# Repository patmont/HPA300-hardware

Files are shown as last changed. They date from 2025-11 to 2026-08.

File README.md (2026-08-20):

# HPA300 replacement controller hardware

An open-hardware, ESP32-S2 replacement control board for the Honeywell HPA300
air purifier. The board preserves the original front-panel layout while adding
USB-C, native USB programming, and a controller designed for the companion
[HPA300 firmware](https://github.com/patmont/HPA300-firmware).

<p align="center">
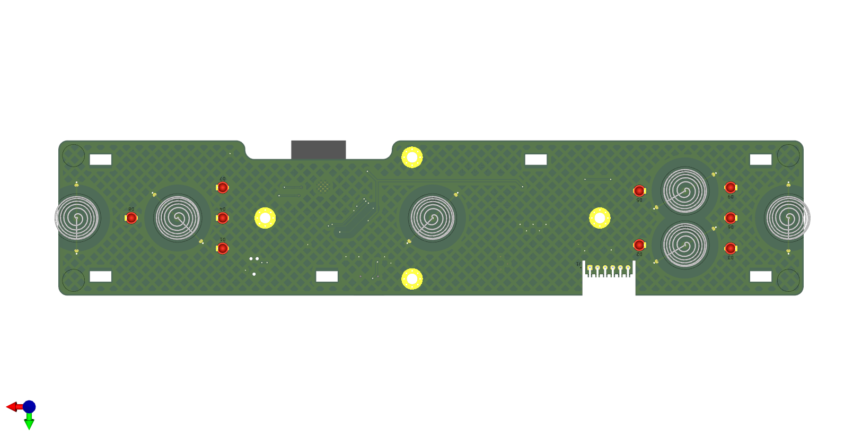
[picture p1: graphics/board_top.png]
HPA300 controller board, front view
  
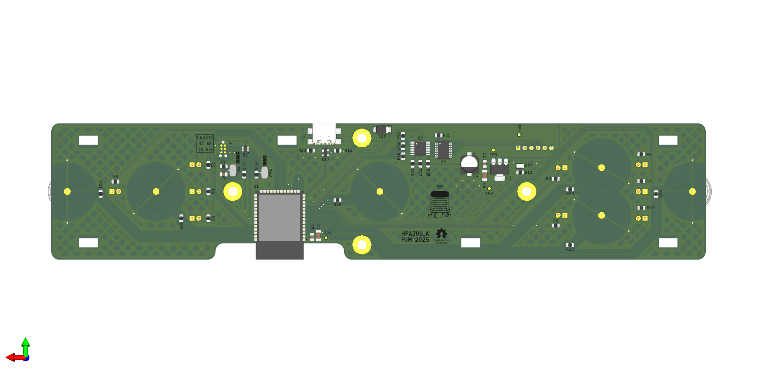
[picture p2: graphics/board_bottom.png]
HPA300 controller board, rear view
  
</p>

> [!IMPORTANT]
> This is an independent community project. It is not affiliated with,
> authorized by, or endorsed by Honeywell International Inc. Build and install
> it at your own risk.

## Downloads

| I want to... | Get this |
| --- | --- |
| Read the circuit | [Schematic PDF](HPA300.pdf) |
| Order the parts | [DigiKey shared list](https://www.digikey.com/en/mylists/list/1ANK154NOU) or [versioned BOM](manufacturing/Assembly/HPA300-bom.csv) |
| Order a bare PCB | Download the `HPA300-<version>-gerbers.zip` asset from the [latest release](https://github.com/patmont/HPA300-hardware/releases/latest) |
| Modify the design | Open [HPA300.kicad_pro](HPA300.kicad_pro) in KiCad 9 |
| Build or flash firmware | Visit [HPA300-firmware](https://github.com/patmont/HPA300-firmware) |

Release assets are the recommended manufacturing handoff because they are tied
to a tagged revision and include SHA-256 checksums. The files under
`manufacturing/` are reviewable snapshots; do not mix them with source files
from a different commit.

## Hardware overview

- ESP32-S2-SOLO-2 controller with native USB-C
- Six capacitive-touch keys matching the original control panel
- Nine front-panel indicators with PWM brightness control
- 74HC238 fan-speed selection with a hardware-disabled default state
- Boot, reset, Tag-Connect programming, and power test access
- Two-layer, 1.6 mm PCB designed in KiCad 9
- Approximately 245 mm × 51 mm overall outline, including the shaped edges

The current checked-in design is revision A and corresponds to the as-built
board. Before ordering, inspect the schematic, board outline, connector
orientation, and your purifier revision. This project has not been evaluated or
certified by a safety agency.

## Manufacturing

For a bare PCB, upload only the release's Gerber archive to the fabricator. It
contains copper, solder mask, paste, silkscreen, edge cuts, plated drills, and
non-plated drills. The archive is generated from the tracked files in
[`manufacturing/Fabrication`](manufacturing/Fabrication/).

The [DigiKey list](https://www.digikey.com/en/mylists/list/1ANK154NOU) is the
most convenient shopping list. The repository BOM is version controlled so a
release remains reproducible even if the shared list later changes. Check stock,
manufacturer part numbers, substitutions, and do-not-populate items before
ordering.

The current repository does **not** claim to be a turnkey PCBA package. An
assembly house will also need a placement/centroid file, confirmed rotations,
assembly drawings, and instructions for the through-hole and mechanical parts.
See [manufacturing/README.md](manufacturing/README.md) for the artifact manifest
and release procedure.

To build the same release assets locally from PowerShell:

```powershell
./scripts/package-release.ps1 -Version v0.1.0
```

The packages are written to `dist/`, which is intentionally ignored by Git.
Pushing a `v*` tag runs the same packager in GitHub Actions and creates a GitHub
release with the Gerber ZIP, schematic PDF, BOM, license notice, and checksum
manifest.

## Repository layout

```text
HPA300.kicad_pro         KiCad project entry point
HPA300.kicad_pcb         Editable PCB source
HPA300.kicad_sch         Root schematic and hierarchical sheets
*.kicad_sch
lib/                     Project-specific symbols, footprints, and 3D models
graphics/                Board renders, logo, and open-hardware mark
manufacturing/
  Fabrication/           Gerber and drill snapshot
  Assembly/              Version-controlled BOM
scripts/                 Reproducible release packaging
.github/workflows/       CI and tagged-release automation
```

KiCad backups, local preferences, caches, downloaded datasheets, and generated
release archives are excluded from version control. Custom symbols, footprints,
and 3D models required to open the project are kept in `lib/`.

## Contributing

Open an issue before making a change that affects the board outline, original
appliance interface, fan safety behavior, or manufacturing stack-up. For a
design change, update the editable KiCad source first, run KiCad's electrical
and design-rule checks, then regenerate the PDF, BOM, Gerbers, and drill files
together. Include the KiCad version and rule-check results in the pull request.

## License and attribution

The hardware design and associated source are licensed under the
[CERN Open Hardware Licence Version 2 – Weakly Reciprocal](LICENSE). You may
study, modify, make, and sell products based on the design, but the license
requires preservation of notices and corresponding-source obligations. See
[NOTICE.md](NOTICE.md) for the copyright, source-location, attribution, and
trademark notices that travel with the design.

Commercial use cannot be prohibited while also calling the project open-source
hardware. The reciprocal license and source-location notice are intended to
ensure that commercial derivatives remain attributable and that their design
changes are available to recipients.

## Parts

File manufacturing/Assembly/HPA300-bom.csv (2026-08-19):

Reference | Qty | Value | DNP | Exclude from BOM | Exclude from Board | Footprint | Datasheet | Digikey
C1 | 1 | 22uF |  |  |  | Capacitor_SMD:C_1206_3216Metric | ~ | CL31A226KAHNNNE
C2,C5 | 2 | 1uF |  |  |  | Capacitor_SMD:C_0805_2012Metric | ~ | GRM21BR61C105MA01L
C3 | 1 | 0.1uF |  |  |  | Capacitor_SMD:C_0805_2012Metric | ~ | KGM21KR51H104KU
C4 | 1 | 100uF |  |  |  | Capacitor_SMD:CP_Elec_6.3x5.8 | https://www.nichicon.co.jp/english/series_items/catalog_pdf/e-uud.pdf | UUD1C101MCL1GS
C6 | 1 | 4.7uF |  |  |  | Capacitor_SMD:C_1206_3216Metric | ~ | GRM319R61H475KA12D
D1 | 1 | LED1 |  |  |  | LED_THT:LED_D3.0mm | ~ | 151031SS04000
D2 | 1 | LED2 |  |  |  | LED_THT:LED_D3.0mm | ~ | 151031SS04000
D3 | 1 | LED3 |  |  |  | LED_THT:LED_D3.0mm | ~ | 151031SS04000
D4 | 1 | LED4 |  |  |  | LED_THT:LED_D3.0mm | ~ | 151031SS04000
D5 | 1 | LED5 |  |  |  | LED_THT:LED_D3.0mm | ~ | 151031SS04000
D6 | 1 | LED6 |  |  |  | LED_THT:LED_D3.0mm | ~ | 151031SS04000
D7 | 1 | LED7 |  |  |  | LED_THT:LED_D3.0mm | ~ | 151031SS04000
D8 | 1 | LED8 |  |  |  | LED_THT:LED_D3.0mm | ~ | 151031SS04000
D9 | 1 | LED9 |  |  |  | LED_THT:LED_D3.0mm | ~ | 151031SS04000
D10 | 1 | SS14 |  |  |  | Diode_SMD:D_SMA | https://www.vishay.com/docs/88746/ss12.pdf | B140Q-13-F
D12 | 1 | LED |  |  |  | LED_SMD:LED_0805_2012Metric | ~ | LTST-C170GKT
D13 | 1 | SP0503BAHT |  |  |  | Package_TO_SOT_SMD:SOT-143 | http://www.littelfuse.com/~/media/files/littelfuse/technical%20resources/documents/data%20sheets/sp05xxba.pdf | SP0503BAHTG
H1,H2,H3,H4 | 4 | MountingHole_Pad |  | Excluded from BOM |  | MountingHole:MountingHole_3.5mm_Pad_Via | ~
J1 | 1 | S6B-XH-A |  |  |  | 0_connector:JST_S6B-XH-A |  | S6B-XH-A
J2 | 1 | USB_C_Receptacle_USB2.0_16P |  |  |  | Connector_USB:USB_C_Receptacle_GCT_USB4110 | https://www.usb.org/sites/default/files/documents/usb_type-c.zip | USB4110-GF-A
J3 | 1 | TC2030 |  | Excluded from BOM |  | Connector:Tag-Connect_TC2030-IDC-NL_2x03_P1.27mm_Vertical | https://www.tag-connect.com/wp-content/uploads/bsk-pdf-manager/2019/12/TC2030-IDC-NL-Datasheet-Rev-B.pdf
KEY1,KEY2,KEY3,KEY4,KEY5,KEY6 | 6 | ~ |  |  |  | 0_switch:HPA300 Key
Q1 | 1 | UMH3N |  |  |  | Package_TO_SOT_SMD:SOT-363_SC-70-6 | http://rohmfs.rohm.com/en/products/databook/datasheet/discrete/transistor/digital/emh3t2r-e.pdf | UMH3NFHATN
R1 | 1 | 200 |  |  |  | Resistor_SMD:R_0805_2012Metric | ~ | CRCW0805200RFKEAC
R2,R3,R4,R5,R6,R7,R8,R9,R10 | 9 | 470 |  |  |  | Resistor_SMD:R_0805_2012Metric | ~ | CRGCQ0805J470R
R11 | 1 | 1k |  |  |  | Resistor_SMD:R_0805_2012Metric | ~ | CRCW08051K00FKEA
R12,R13 | 2 | 5.1k |  |  |  | Resistor_SMD:R_0805_2012Metric | ~ | CRCW08055K10FKEA
R14,R15,R16,R17,R18,R19,R20,R21,R22,R23,R24,R25,R26,R27,R28 | 15 | 10k |  |  |  | Resistor_SMD:R_0805_2012Metric | ~ | CRCW080510K0FKEA
SW1 | 1 | RESET |  |  |  | 0_switch:SW_B3U-1100P |  | B3U-1100P
SW2 | 1 | BOOT |  |  |  | 0_switch:SW_B3U-1100P |  | B3U-1100P
TP1 | 1 | GND |  |  |  | TestPoint:TestPoint_Pad_D1.0mm | ~
TP2 | 1 | 3.3V |  |  |  | TestPoint:TestPoint_Pad_D1.0mm | ~
TP3 | 1 | 5V |  |  |  | TestPoint:TestPoint_Pad_D1.0mm | ~
TP4 | 1 | TestPoint |  |  |  | TestPoint:TestPoint_Pad_D1.0mm | ~
U1 | 1 | ESP32-S2-SOLO-2 |  |  |  | 0_mcu:ESP32-S2-SOLO-2 |  | ESP32-S2-SOLO-2-N4
U2 | 1 | CD74HC238PWR |  |  |  | 0_74xx:PW0016A_N | https://www.ti.com/lit/gpn/cd74hc238 | CD74HC238PWR
U3 | 1 | LDL1117-3.3 |  |  |  | Package_TO_SOT_SMD:SOT-223-3_TabPin2 | https://www.st.com/content/ccc/resource/technical/document/datasheet/group3/0e/5a/00/ca/10/1a/4f/a5/DM00366442/files/DM00366442.pdf/jcr:content/translations/e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 | LDL1117S33R
U4 | 1 | TBD62783A |  |  |  | Package_SO:SSOP-18_4.4x6.5mm_P0.65mm | http://toshiba.semicon-storage.com/info/docget.jsp?did=30523&prodName=TBD62783APG | TBD62783AFNG,EL

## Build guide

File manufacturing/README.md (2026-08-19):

# Manufacturing artifacts

This directory contains generated outputs for revision A of the HPA300
replacement controller. Editable design sources live at the repository root;
these files are manufacturing snapshots, not source-of-truth design files.

## Fabrication

`Fabrication/` contains the two copper layers, solder masks, paste layers,
silkscreens, board outline, plated drill file, and non-plated drill file. The
release packager validates the expected manifest and puts these files alone in
the Gerber ZIP so it can be uploaded directly to a quick-turn bare-PCB vendor.

Review the vendor's rendered preview before ordering. In particular, confirm:

- 245 mm × 51 mm approximate overall outline and all internal slots
- two copper layers and 1.6 mm finished board thickness
- plated versus non-plated holes
- front and rear silkscreen orientation
- solder-mask clearances and castellated/mechanical features, if interpreted
  specially by the selected vendor

## Assembly

`Assembly/HPA300-bom.csv` is the version-controlled BOM snapshot. The external
[DigiKey list](https://www.digikey.com/en/mylists/list/1ANK154NOU) is convenient
for purchasing but can change independently of a tagged hardware release.

This is not yet a complete contract-assembly handoff. Before requesting turnkey
PCBA, generate and verify at least:

- a component placement/centroid (CPL or position) file
- assembly drawings for both sides
- rotations and package orientations against the assembler's conventions
- fitted/not-fitted status and approved substitutions
- instructions for through-hole LEDs, touch springs, connector, and mechanical
  parts

## Making a release

1. Open the project in KiCad 9 and run electrical- and design-rule checks.
2. Regenerate the schematic PDF, BOM, Gerbers, and drill files from the same
   clean revision.
3. Inspect the Gerbers in an independent viewer and compare the BOM with the
   schematic and DigiKey list.
4. Run `./scripts/package-release.ps1 -Version vX.Y.Z` and inspect `dist/`.
5. Commit the generated snapshots, tag that exact commit with `vX.Y.Z`, and
   push the tag. GitHub Actions creates the release and attaches the artifacts.

Do not create a release by combining generated outputs from different commits.

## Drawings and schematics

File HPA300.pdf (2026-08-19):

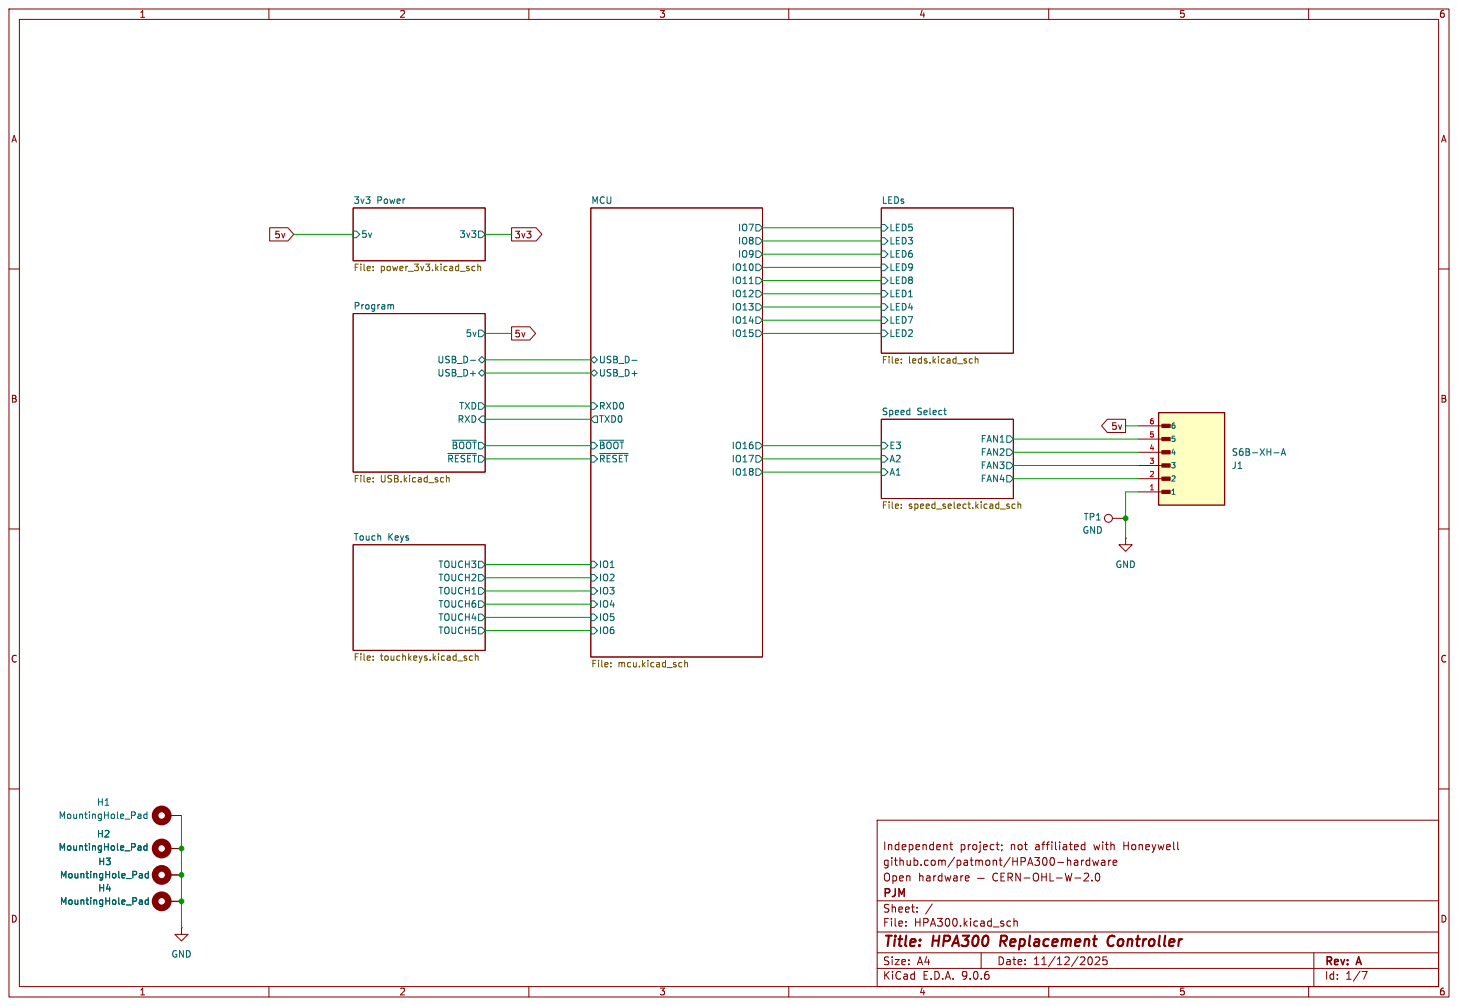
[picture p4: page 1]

File: USB.kicad_schTOUCH1 TOUCH2 TOUCH3 TOUCH4 TOUCH5 TOUCH6 Touch Keys File: touchkeys.kicad_sch

github.com/patmont/HPA300-hardware
Id: 1/7 Title: HPA300 Replacement Controller File: HPA300.kicad_sch Sheet: / PJM

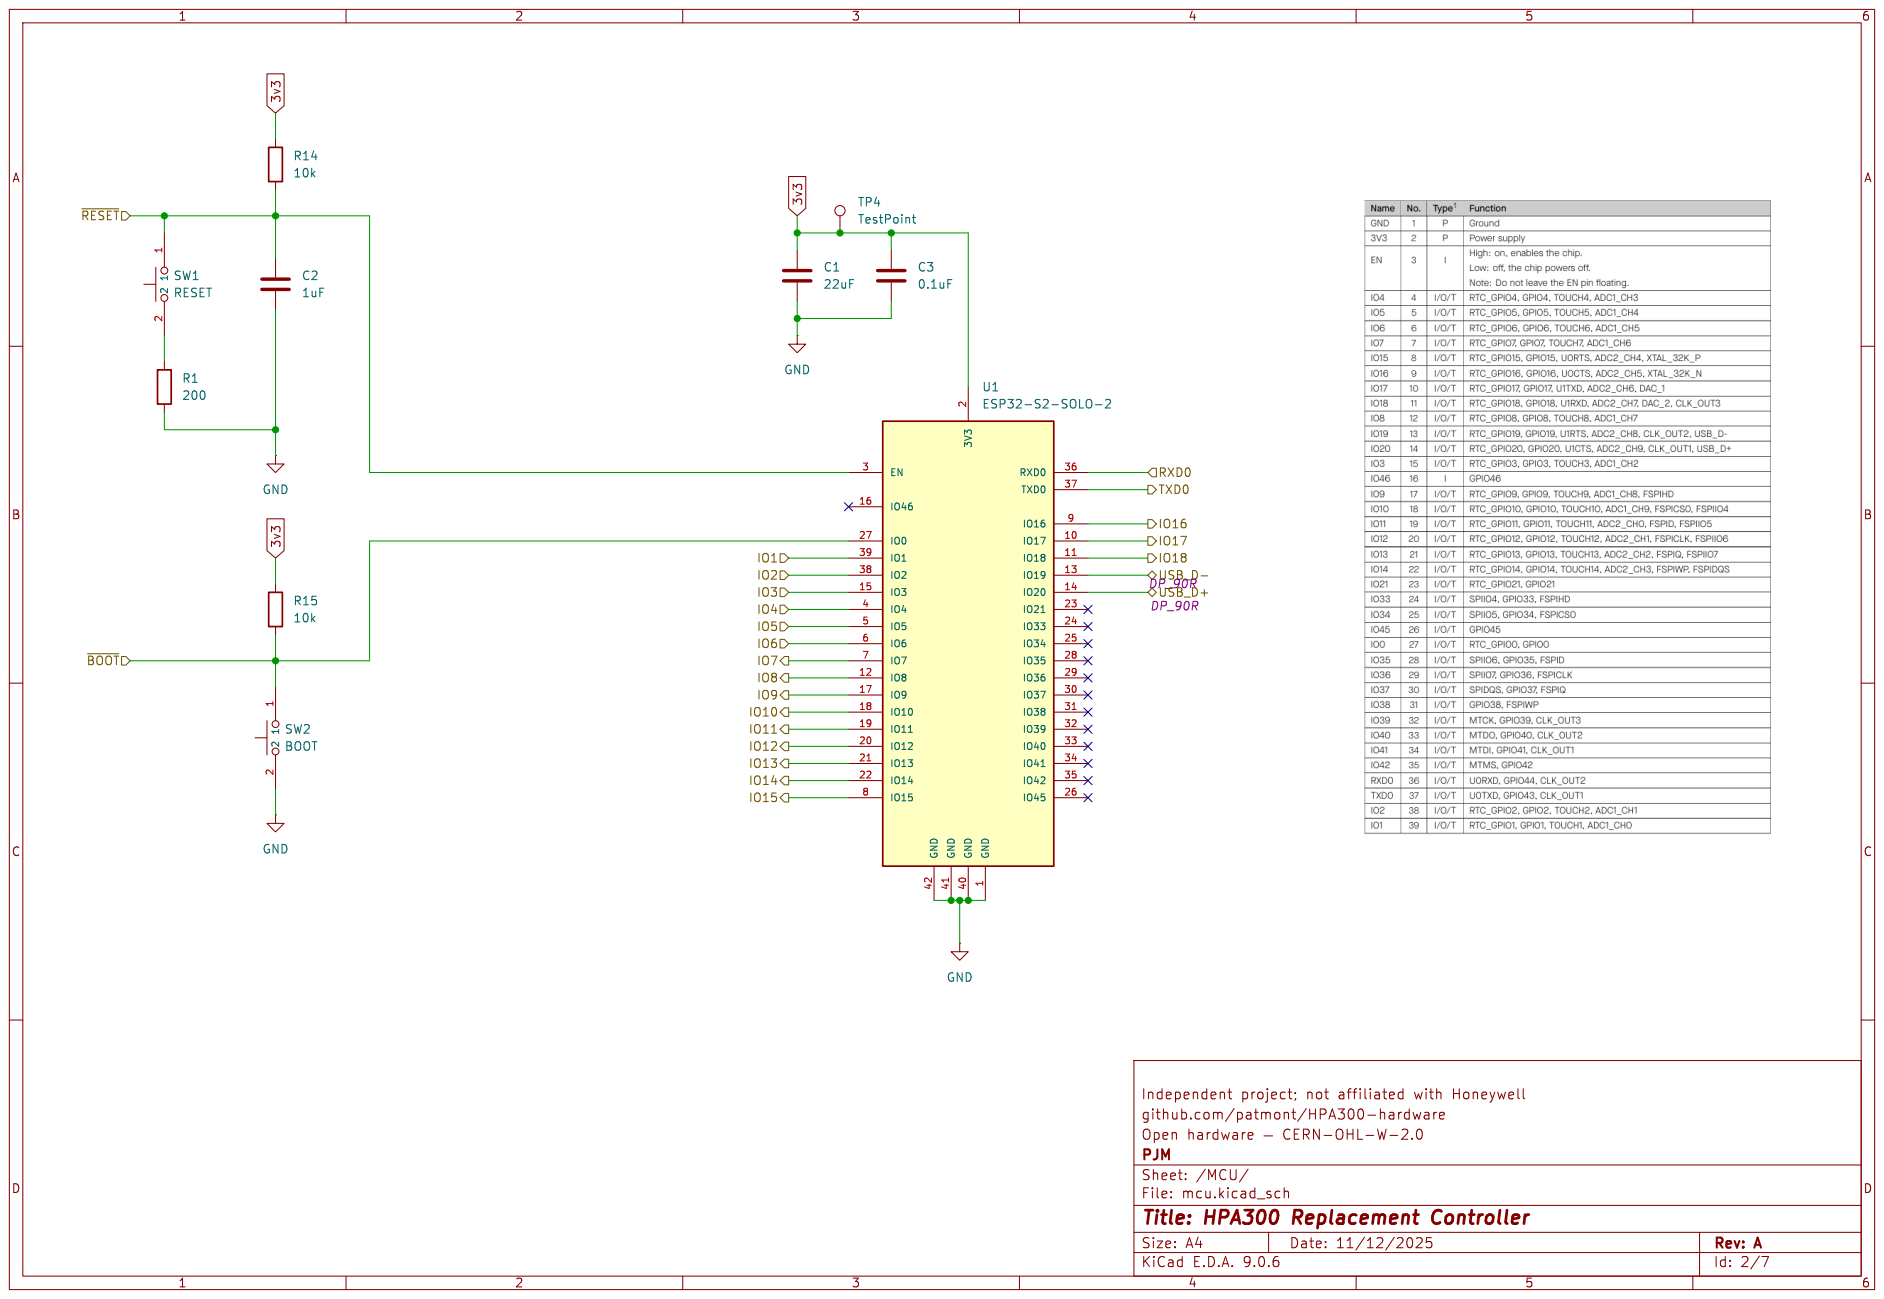
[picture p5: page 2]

github.com/patmont/HPA300-hardware
Id: 2/7 Title: HPA300 Replacement Controller File: mcu.kicad_sch Sheet: /MCU/ PJM

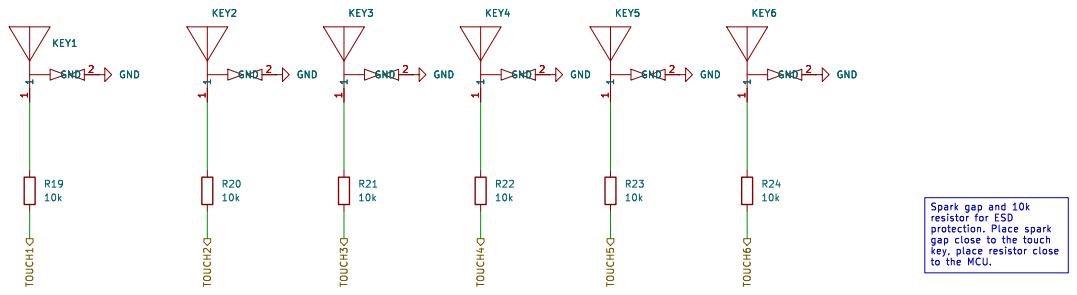
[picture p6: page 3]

github.com/patmont/HPA300-hardware

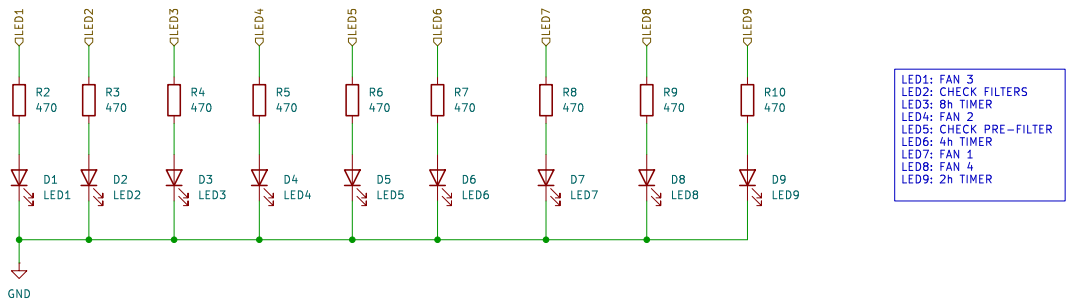
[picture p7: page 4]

github.com/patmont/HPA300-hardware
Id: 4/7 Title: HPA300 Replacement Controller File: leds.kicad_sch Sheet: /LEDs/ PJM

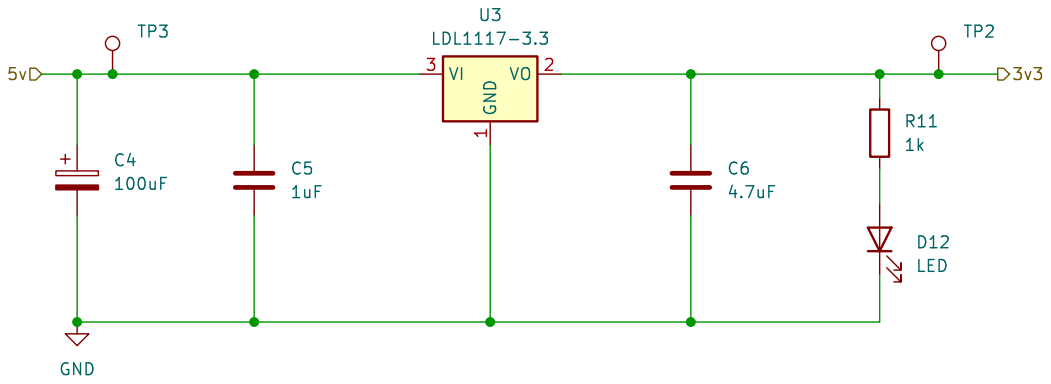
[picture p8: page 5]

github.com/patmont/HPA300-hardware

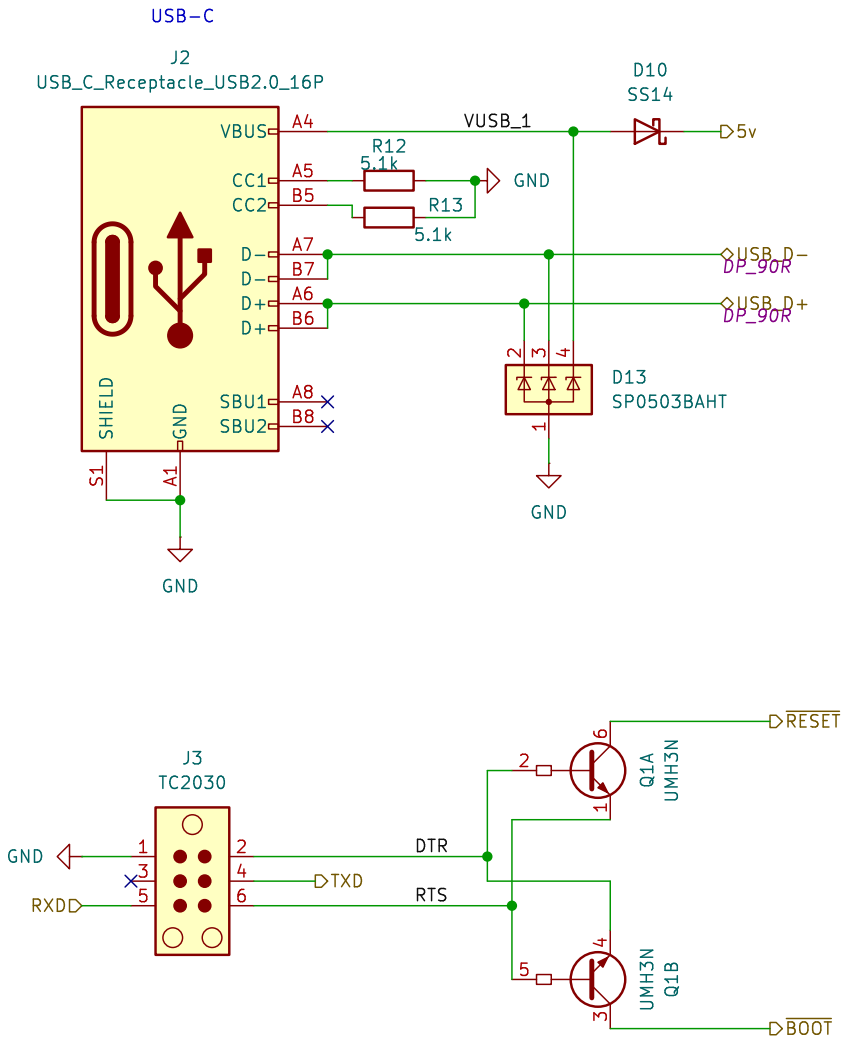
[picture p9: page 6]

github.com/patmont/HPA300-hardware
Id: 6/7 Title: HPA300 Replacement Controller File: USB.kicad_sch Sheet: /Program/ PJM

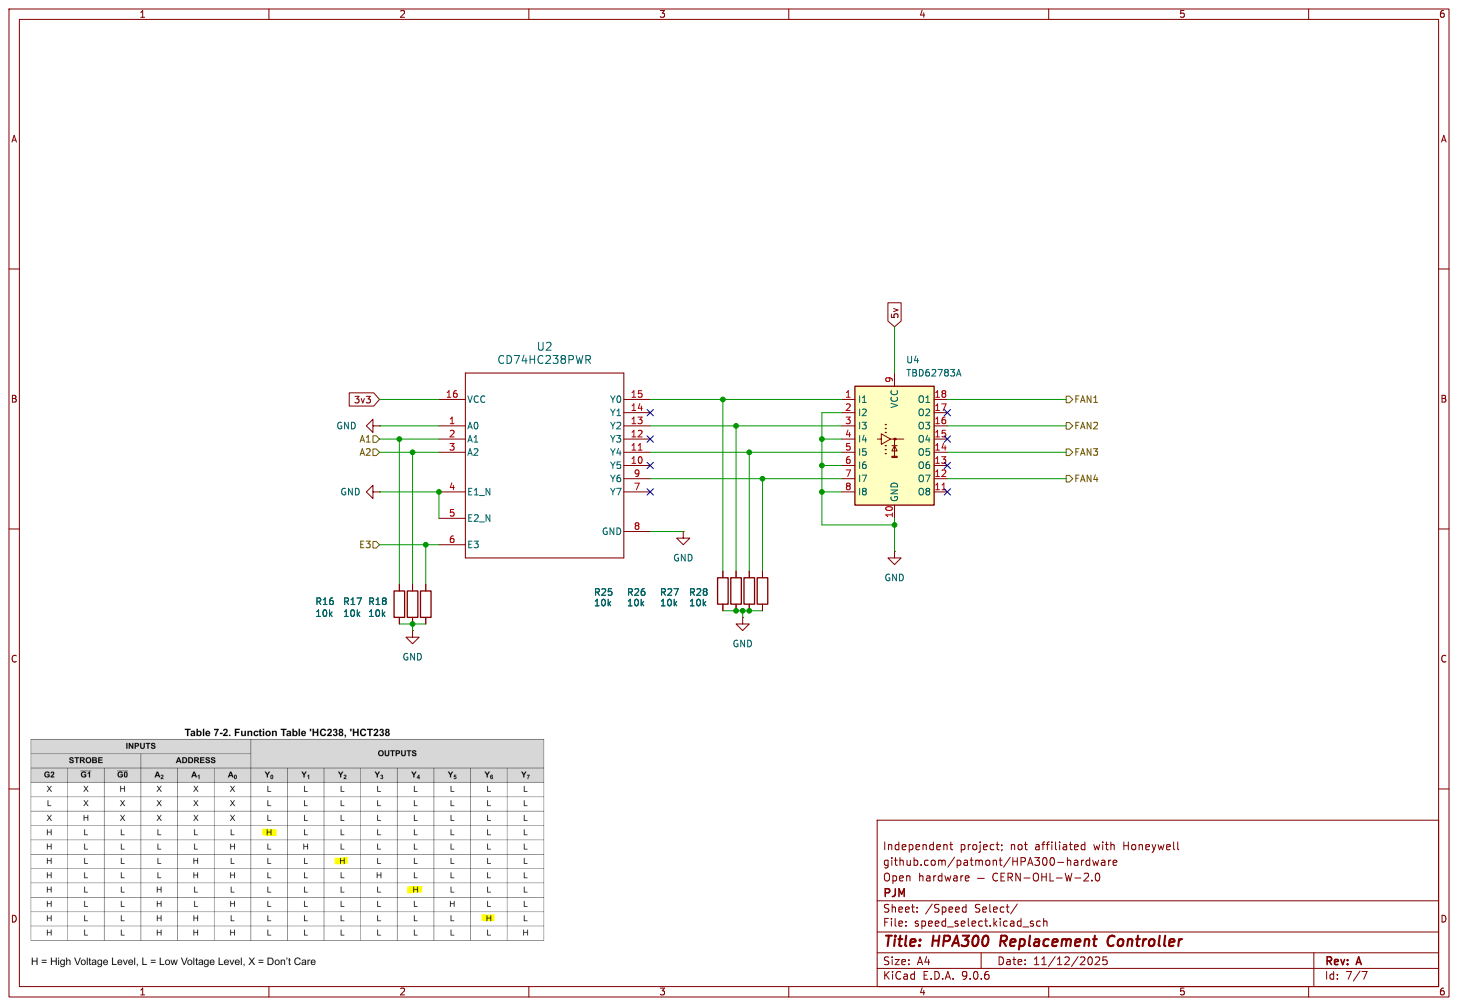
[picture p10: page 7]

github.com/patmont/HPA300-hardware

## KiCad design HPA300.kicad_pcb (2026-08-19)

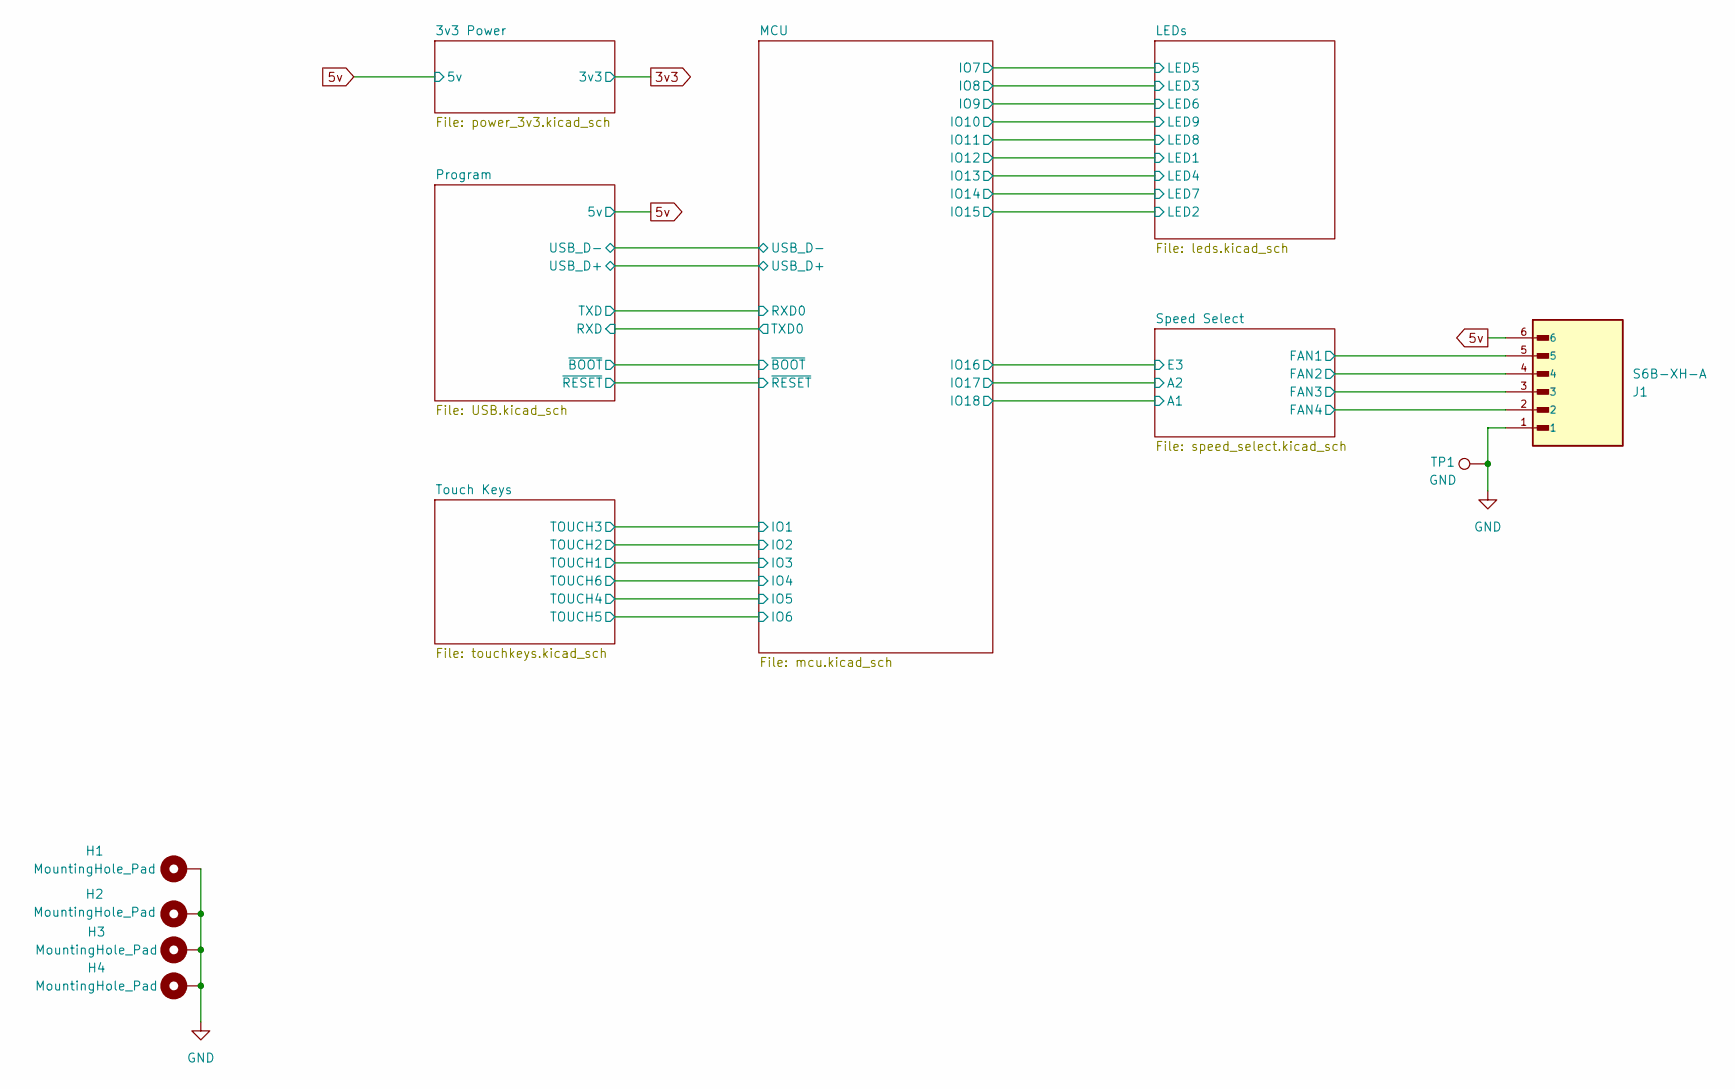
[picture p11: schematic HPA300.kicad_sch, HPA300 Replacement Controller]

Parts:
H1, H2, H3, H4: MountingHole_Pad; MountingHole_3.5mm_Pad_Via
J1: S6B-XH-A; JST_S6B-XH-A; Digikey S6B-XH-A
TP1: GND; TestPoint_Pad_D1.0mm

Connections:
5v: J1.6; also elsewhere on the board
/Speed Select/FAN1: J1.5; also elsewhere on the board
/Speed Select/FAN2: J1.4; also elsewhere on the board
/Speed Select/FAN3: J1.3; also elsewhere on the board
/Speed Select/FAN4: J1.2; also elsewhere on the board
GND: H1.1, H2.1, H3.1, H4.1, J1.1, TP1.1; also elsewhere on the board

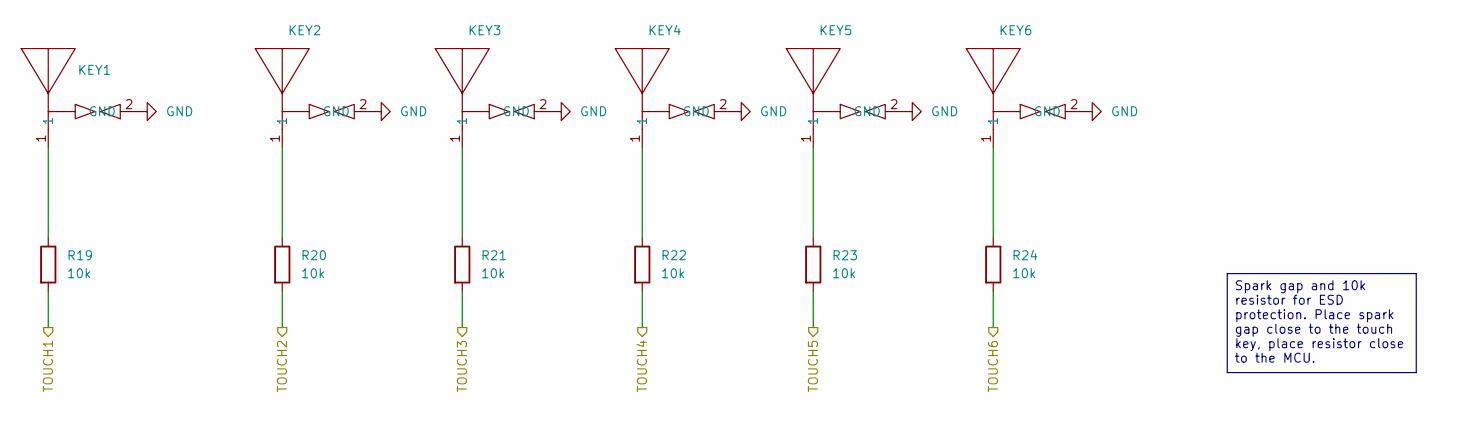
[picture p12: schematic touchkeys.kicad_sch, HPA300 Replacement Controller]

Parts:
KEY1, KEY2, KEY3, KEY4, KEY5, KEY6: HPA300 Key
R19, R20, R21, R22, R23, R24: 10k; R_0805_2012Metric; Digikey CRCW080510K0FKEA

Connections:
/MCU/IO1: R21.2; also elsewhere on the board
/MCU/IO2: R20.2; also elsewhere on the board
/MCU/IO3: R19.2; also elsewhere on the board
/MCU/IO4: R24.2; also elsewhere on the board
/MCU/IO5: R22.2; also elsewhere on the board
/MCU/IO6: R23.2; also elsewhere on the board
GND: KEY1.2 (GND), KEY2.2 (GND), KEY3.2 (GND), KEY4.2 (GND), KEY5.2 (GND), KEY6.2 (GND); also elsewhere on the board
unnamed: KEY1.1, R19.1
unnamed: KEY2.1, R20.1
unnamed: KEY3.1, R21.1
unnamed: KEY4.1, R22.1
unnamed: KEY5.1, R23.1
unnamed: KEY6.1, R24.1

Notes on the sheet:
Spark gap and 10k resistor for ESD protection. Place spark gap close to the touch key, place resistor close to the MCU.

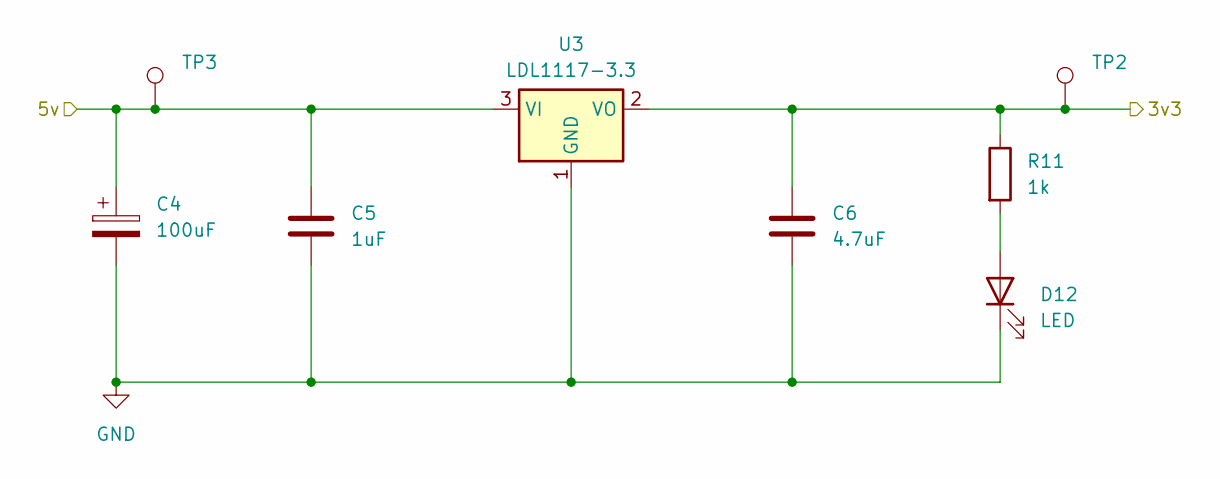
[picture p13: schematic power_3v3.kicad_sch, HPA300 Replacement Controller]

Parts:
C4: 100uF; CP_Elec_6.3x5.8; Digikey UUD1C101MCL1GS
C5: 1uF; C_0805_2012Metric; Digikey GRM21BR61C105MA01L
C6: 4.7uF; C_1206_3216Metric; Digikey GRM319R61H475KA12D
D12: LED; LED_0805_2012Metric; Digikey LTST-C170GKT
R11: 1k; R_0805_2012Metric; Digikey CRCW08051K00FKEA
TP2: 3.3V; TestPoint_Pad_D1.0mm
TP3: 5V; TestPoint_Pad_D1.0mm
U3: LDL1117-3.3; SOT-223-3_TabPin2; Digikey LDL1117S33R

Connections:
3v3: C6.1, R11.1, TP2.1, U3.2 (VO); also elsewhere on the board
5v: C4.1, C5.1, TP3.1, U3.3 (VI); also elsewhere on the board
GND: C4.2, C5.2, C6.2, D12.1 (K), U3.1 (GND); also elsewhere on the board
unnamed: D12.2 (A), R11.2

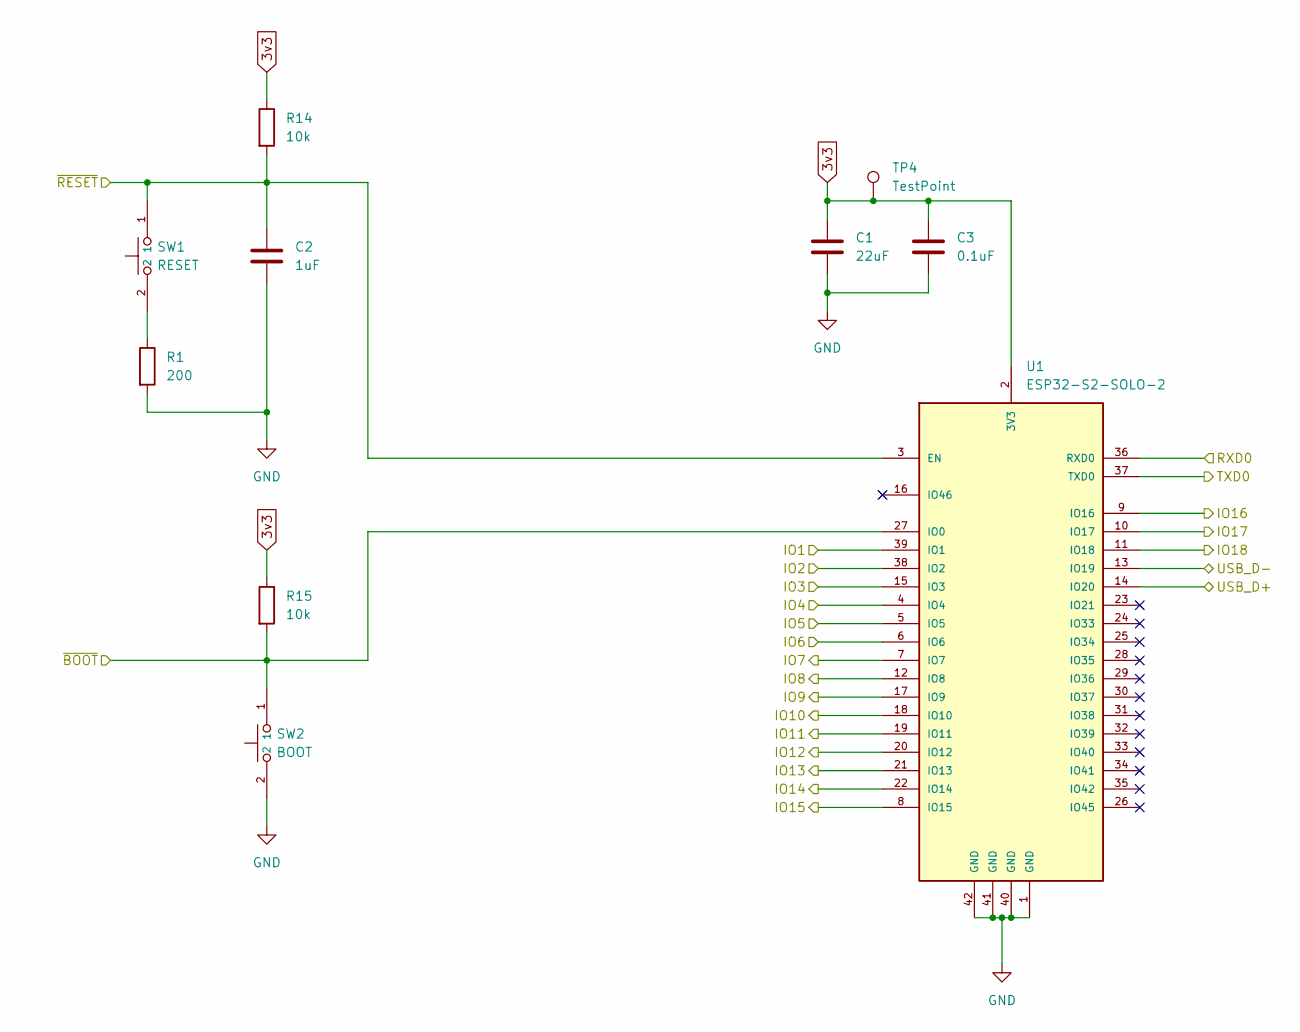
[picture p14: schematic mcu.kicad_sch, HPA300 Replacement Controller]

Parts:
C1: 22uF; C_1206_3216Metric; Digikey CL31A226KAHNNNE
C2: 1uF; C_0805_2012Metric; Digikey GRM21BR61C105MA01L
C3: 0.1uF; C_0805_2012Metric; Digikey KGM21KR51H104KU
R1: 200; R_0805_2012Metric; Digikey CRCW0805200RFKEAC
R14, R15: 10k; R_0805_2012Metric; Digikey CRCW080510K0FKEA
SW1: RESET; SW_B3U-1100P; Digikey B3U-1100P
SW2: BOOT; SW_B3U-1100P; Digikey B3U-1100P
TP4: TestPoint; TestPoint_Pad_D1.0mm
U1: ESP32-S2-SOLO-2; PARTREV 1.6; Digikey ESP32-S2-SOLO-2-N4

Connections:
3v3: C1.1, C3.1, R14.1, R15.1, TP4.1, U1.2 (3V3); also elsewhere on the board
/LEDs/LED1: U1.20 (IO12); also elsewhere on the board
/LEDs/LED2: U1.8 (IO15); also elsewhere on the board
/LEDs/LED3: U1.12 (IO8); also elsewhere on the board
/LEDs/LED4: U1.21 (IO13); also elsewhere on the board
/LEDs/LED5: U1.7 (IO7); also elsewhere on the board
/LEDs/LED6: U1.17 (IO9); also elsewhere on the board
/LEDs/LED7: U1.22 (IO14); also elsewhere on the board
/LEDs/LED8: U1.19 (IO11); also elsewhere on the board
/LEDs/LED9: U1.18 (IO10); also elsewhere on the board
/MCU/IO1: U1.39 (IO1); also elsewhere on the board
/MCU/IO2: U1.38 (IO2); also elsewhere on the board
/MCU/IO3: U1.15 (IO3); also elsewhere on the board
/MCU/IO4: U1.4 (IO4); also elsewhere on the board
/MCU/IO5: U1.5 (IO5); also elsewhere on the board
/MCU/IO6: U1.6 (IO6); also elsewhere on the board
/MCU/IO16: U1.9 (IO16); also elsewhere on the board
/MCU/IO17: U1.10 (IO17); also elsewhere on the board
/MCU/IO18: U1.11 (IO18); also elsewhere on the board
/MCU/RXD0: U1.36 (RXD0); also elsewhere on the board
/MCU/TXD0: U1.37 (TXD0); also elsewhere on the board
/MCU/USB_D+: U1.14 (IO20); also elsewhere on the board
/MCU/USB_D-: U1.13 (IO19); also elsewhere on the board
/MCU/~BOOT: R15.2, SW2.1, U1.27 (IO0); also elsewhere on the board
/MCU/~RESET: C2.1, R14.2, SW1.1, U1.3 (EN); also elsewhere on the board
GND: C1.2, C2.2, C3.2, R1.2, SW2.2, U1.1 (GND), U1.40 (GND), U1.41 (GND), U1.42 (GND); also elsewhere on the board
unnamed: R1.1, SW1.2

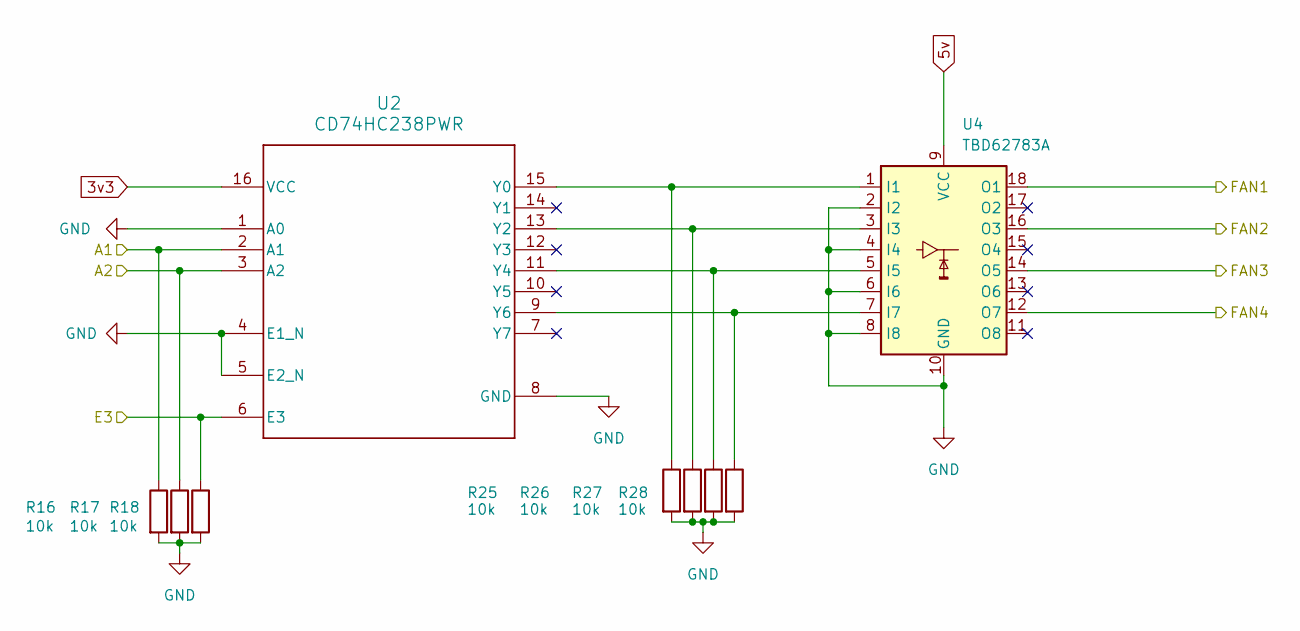
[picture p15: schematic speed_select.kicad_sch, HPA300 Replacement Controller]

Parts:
R16, R17, R18, R25, R26, R27, R28: 10k; R_0805_2012Metric; Digikey CRCW080510K0FKEA
U2: CD74HC238PWR; PW0016A_N; Digikey CD74HC238PWR
U4: TBD62783A; SSOP-18_4.4x6.5mm_P0.65mm; Digikey TBD62783AFNG,EL

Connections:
3v3: U2.16 (VCC); also elsewhere on the board
5v: U4.9 (VCC); also elsewhere on the board
/MCU/IO16: R18.1, U2.6 (E3); also elsewhere on the board
/MCU/IO17: R17.1, U2.3 (A2); also elsewhere on the board
/MCU/IO18: R16.1, U2.2 (A1); also elsewhere on the board
/Speed Select/FAN1: U4.18 (O1); also elsewhere on the board
/Speed Select/FAN2: U4.16 (O3); also elsewhere on the board
/Speed Select/FAN3: U4.14 (O5); also elsewhere on the board
/Speed Select/FAN4: U4.12 (O7); also elsewhere on the board
GND: R16.2, R17.2, R18.2, R25.2, R26.2, R27.2, R28.2, U2.1 (A0), U2.4 (E1_N), U2.5 (E2_N), U2.8 (GND), U4.2 (I2), U4.4 (I4), U4.6 (I6), U4.8 (I8), U4.10 (GND); also elsewhere on the board
unnamed: R25.1, U2.15 (Y0), U4.1 (I1)
unnamed: R26.1, U2.13 (Y2), U4.3 (I3)
unnamed: R27.1, U2.11 (Y4), U4.5 (I5)
unnamed: R28.1, U2.9 (Y6), U4.7 (I7)

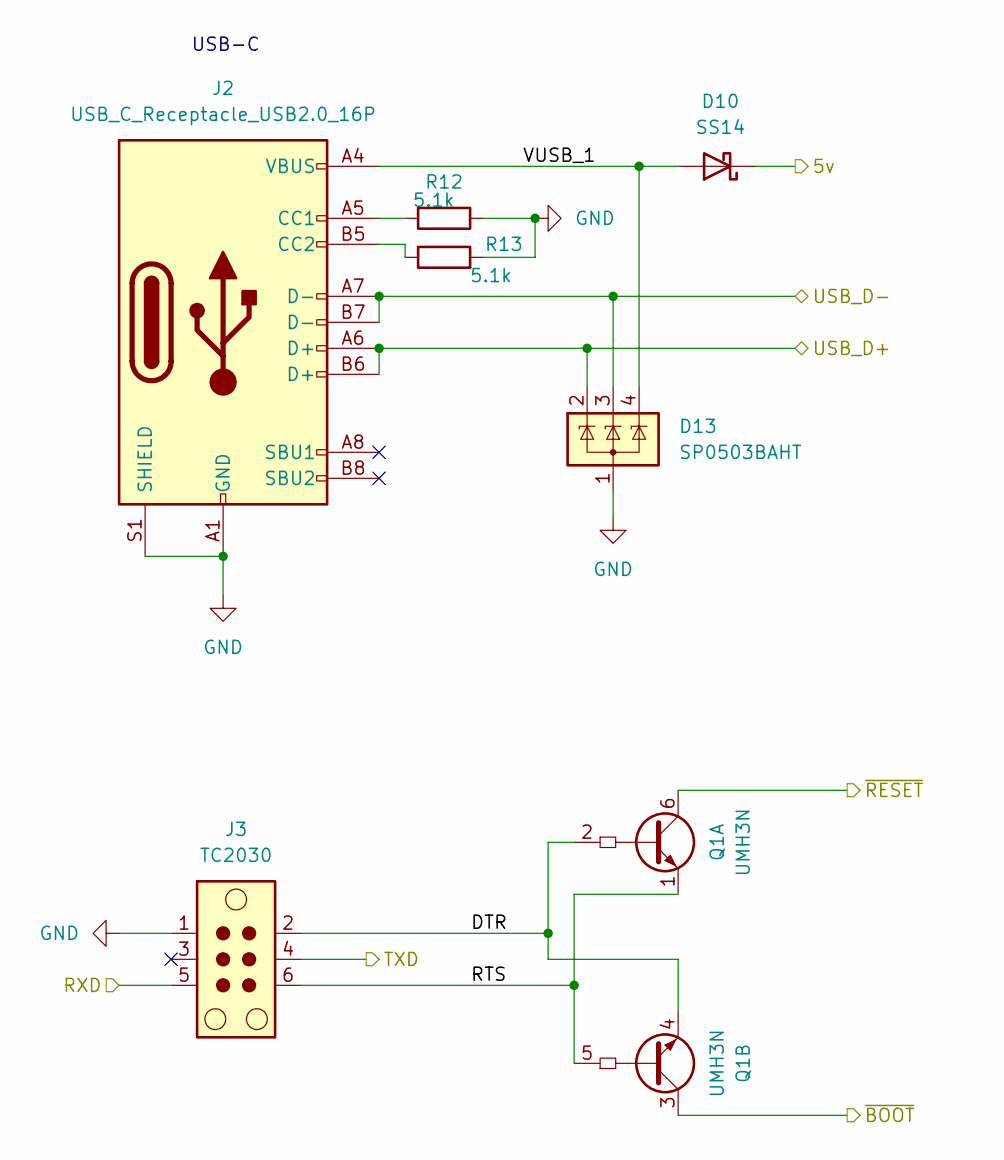
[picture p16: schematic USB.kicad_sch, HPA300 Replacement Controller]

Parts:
D10: SS14; D_SMA; Digikey B140Q-13-F
D13: SP0503BAHT; SOT-143; Digikey SP0503BAHTG
J2: USB_C_Receptacle_USB2.0_16P; USB_C_Receptacle_GCT_USB4110; Digikey USB4110-GF-A
J3: TC2030; Tag-Connect_TC2030-IDC-NL_2x03_P1.27mm_Vertical
Q1: UMH3N; SOT-363_SC-70-6; Digikey UMH3NFHATN
R12, R13: 5.1k; R_0805_2012Metric; Digikey CRCW08055K10FKEA

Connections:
5v: D10.1 (K); also elsewhere on the board
/MCU/RXD0: J3.4; also elsewhere on the board
/MCU/TXD0: J3.5; also elsewhere on the board
/MCU/USB_D+: D13.2 (K), J2.A6 (D+), J2.B6 (D+); also elsewhere on the board
/MCU/USB_D-: D13.3 (K), J2.A7 (D-), J2.B7 (D-); also elsewhere on the board
/MCU/~BOOT: Q1.3 (C2); also elsewhere on the board
/MCU/~RESET: Q1.6 (C1); also elsewhere on the board
/Program/DTR: J3.2, Q1.2 (B1), Q1.4 (E2)
/Program/RTS: J3.6, Q1.1 (E1), Q1.5 (B2)
/Program/VUSB_1: D10.2 (A), D13.4 (K), J2.A4 (VBUS), J2.A9 (VBUS), J2.B4 (VBUS), J2.B9 (VBUS)
GND: D13.1 (A), J2.A1 (GND), J2.A12 (GND), J2.B1 (GND), J2.B12 (GND), J2.S1 (SHIELD), J3.1, R12.1, R13.2; also elsewhere on the board
unnamed: J2.A5 (CC1), R12.2
unnamed: J2.B5 (CC2), R13.1

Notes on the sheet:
USB-C

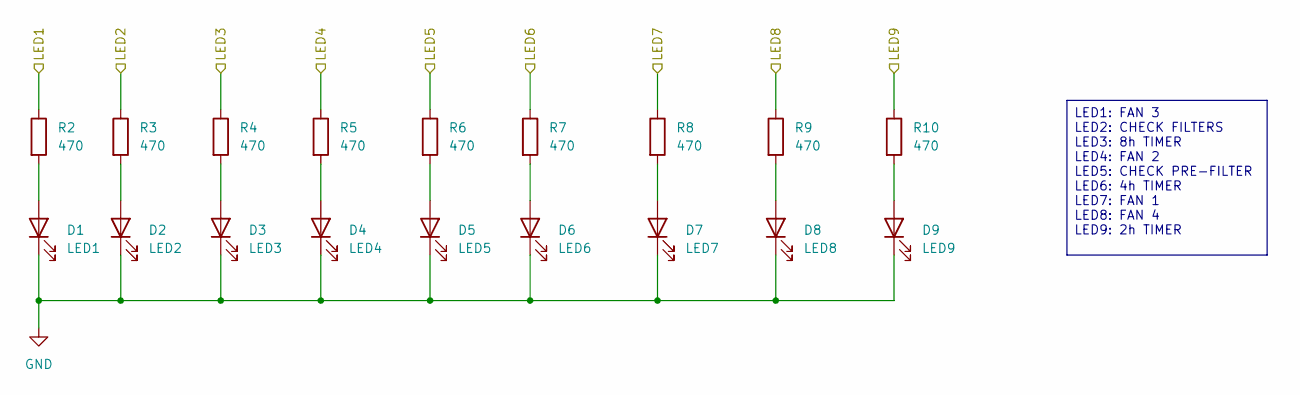
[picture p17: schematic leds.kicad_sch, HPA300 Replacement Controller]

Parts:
D1: LED1; LED_D3.0mm; Digikey 151031SS04000
D2: LED2; LED_D3.0mm; Digikey 151031SS04000
D3: LED3; LED_D3.0mm; Digikey 151031SS04000
D4: LED4; LED_D3.0mm; Digikey 151031SS04000
D5: LED5; LED_D3.0mm; Digikey 151031SS04000
D6: LED6; LED_D3.0mm; Digikey 151031SS04000
D7: LED7; LED_D3.0mm; Digikey 151031SS04000
D8: LED8; LED_D3.0mm; Digikey 151031SS04000
D9: LED9; LED_D3.0mm; Digikey 151031SS04000
R2, R3, R4, R5, R6, R7, R8, R9, R10: 470; R_0805_2012Metric; Digikey CRGCQ0805J470R

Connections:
/LEDs/LED1: R2.1; also elsewhere on the board
/LEDs/LED2: R3.1; also elsewhere on the board
/LEDs/LED3: R4.1; also elsewhere on the board
/LEDs/LED4: R5.1; also elsewhere on the board
/LEDs/LED5: R6.1; also elsewhere on the board
/LEDs/LED6: R7.1; also elsewhere on the board
/LEDs/LED7: R8.1; also elsewhere on the board
/LEDs/LED8: R9.1; also elsewhere on the board
/LEDs/LED9: R10.1; also elsewhere on the board
GND: D1.1 (K), D2.1 (K), D3.1 (K), D4.1 (K), D5.1 (K), D6.1 (K), D7.1 (K), D8.1 (K), D9.1 (K); also elsewhere on the board
unnamed: D1.2 (A), R2.2
unnamed: D2.2 (A), R3.2
unnamed: D3.2 (A), R4.2
unnamed: D4.2 (A), R5.2
unnamed: D5.2 (A), R6.2
unnamed: D6.2 (A), R7.2
unnamed: D7.2 (A), R8.2
unnamed: D8.2 (A), R9.2
unnamed: D9.2 (A), R10.2

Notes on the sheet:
LED1: FAN 3 LED2: CHECK FILTERS LED3: 8h TIMER LED4: FAN 2 LED5: CHECK PRE-FILTER LED6: 4h TIMER LED7: FAN 1 LED8: FAN 4 LED9: 2h TIMER

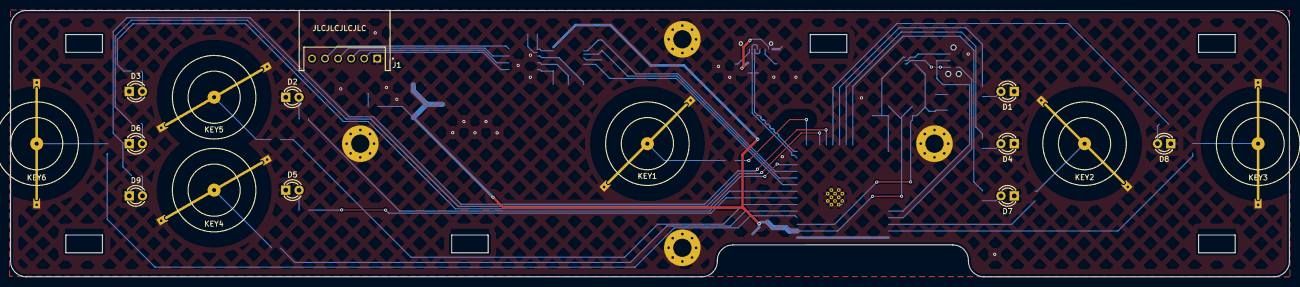
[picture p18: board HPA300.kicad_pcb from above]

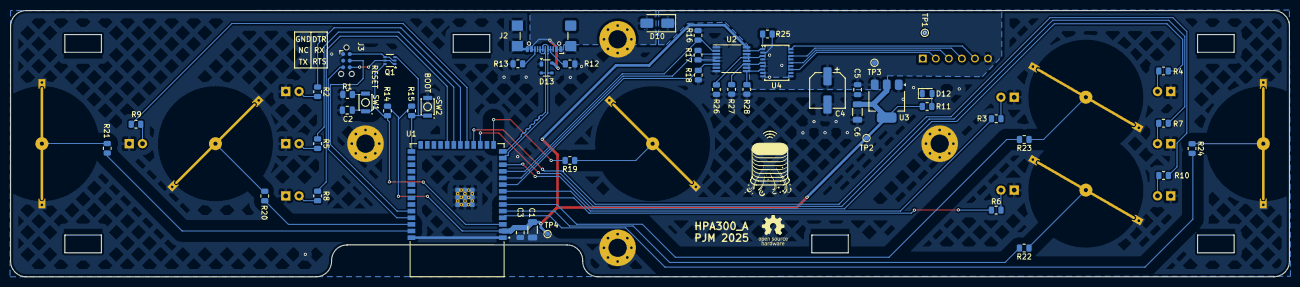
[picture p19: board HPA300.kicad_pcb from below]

Board: 2 copper layers, 245.0 x 51.0 mm, 70 parts (50 on the bottom side), 57 nets.

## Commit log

2025-11-24 Rev A as-built
    Release of the Rev A as-built board files
    [HPA300-B_Cu.gbl, HPA300-B_Mask.gbs, HPA300-B_Paste.gbp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]
2026-08-19 Prepare HPA300 hardware repository for Rev A release.
    [HPA300-bom.csv, HPA300.kicad_pcb, HPA300.kicad_sch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]

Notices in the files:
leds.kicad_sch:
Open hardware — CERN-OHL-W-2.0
